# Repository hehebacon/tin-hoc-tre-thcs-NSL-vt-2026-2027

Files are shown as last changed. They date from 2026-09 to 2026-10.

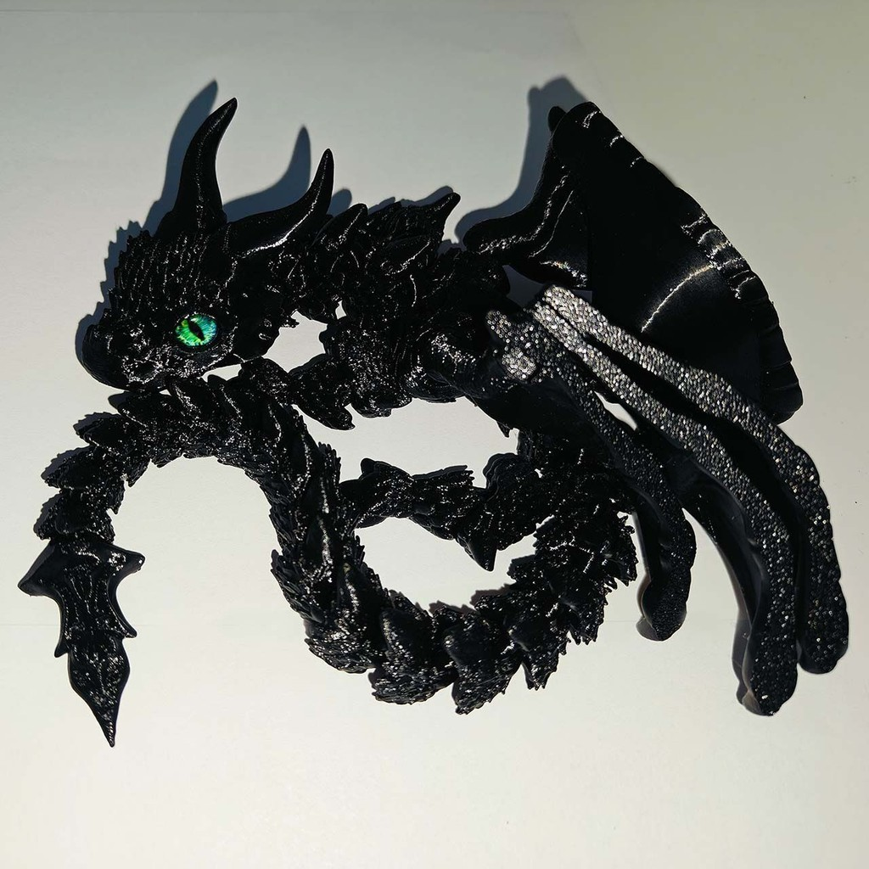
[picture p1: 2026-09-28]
dragon-1.png

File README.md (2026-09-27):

# AI Quadruped Robot - Servo Controller

Current firmware stage:

- ESP32 target
- 4 legs / 12 logical servo channels
- Inverse kinematics module
- Per-servo calibration
- Servo manager
- Serial command/debug interface
- Hardware-independent simulation stage

## Folder

```text
servo_controller/
├── servo_controller.ino
├── config.h
├── Kinematics.h
├── Kinematics.cpp
├── ServoCalibration.h
├── ServoCalibration.cpp
├── ServoManager.h
├── ServoManager.cpp
└── README.md
```

## Arduino IDE

Open:

```text
servo_controller.ino
```

Select the ESP32 board already being used by the project and press Verify.

No PCA9685 library is required yet because the current ServoManager is a software/simulation layer.

## Serial

Baud:

```text
115200
```

Commands:

```text
help
debug
status
center
enable
disable

servo 0 90
leg FL 90 90 90

cal
cal 0
caloffset 0 5
calinvert 1 1
callimit 2 10 170

ik 80 0 -100
ikleg FL 80 0 -100
```

## Important

Do not connect or power real servos yet.

The next hardware stage is:

```text
ServoManager
    ↓
PCA9685
    ↓
12 servos
```

That stage will require correct power wiring and current handling.

## Current firmware architecture (v0.4.0)

The firmware now contains:
- hardware-independent quadruped core, kinematics, gait and servo calibration
- deterministic offline competition DecisionEngine
- Perception / WorldState abstraction for line, obstacle, target and color
- color and line sensor adapter interfaces
- local Vietnamese/English offline command AI
- ESP32 Wi-Fi AP + optional STA Internet connection
- optional Gemini online assistant with offline fallback
- web dashboard and telemetry
- safety layer remains authoritative over motion

Online AI is optional. Competition autonomy must not depend on Internet access.

Real-hardware status: the software interfaces are ready for integration, but sensor drivers, pickup/place hardware, field calibration and repeated real-robot testing are still required before claiming competition-ready hardware performance.

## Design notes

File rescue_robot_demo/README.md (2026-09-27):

# Rescue Robot Simulator V3

This directory contains the hardware-neutral rescue robot simulator and the
ESP32 motion boundary.

## What is included

- deterministic 50 ms simulator loop
- A* navigation with terrain cost
- alternating-diagonal quadruped gait
- gait movesets: IDLE, WALK, SLOW_WALK, SEARCH, RESCUE
- foot-target -> hardware-aligned IK -> joint-angle telemetry
- live leg moveset/phase visualization and joint-angle display
- ESP32 MotionController gait execution
- calibration remains between IK and servo output
- E-STOP / resume path
- telemetry and serial command protocol
- unit tests for navigation, gait and safety

## Motion architecture

Simulator:

    mission/path
        -> GaitPlanner
        -> FootTarget
        -> QuadrupedIK (45/75/105 mm)
        -> joint angles

ESP32:

    GaitController
        -> FootTarget
        -> MotionController
        -> Kinematics
        -> ServoCalibration
        -> ServoManager
        -> PCA9685

The simulator is not a replacement for mechanical calibration. Before real
servo power-up, verify every leg's direction, limits, neutral angle and physical
clearance at low speed.

## Run

    ./run.sh

## Test

    python3 -m unittest discover -s . -p 'test_*.py'

## Serial gait commands

    gait WALK
    gait SLOW_WALK
    gait SEARCH
    gait RESCUE
    stop
    resume

JSON command example:

    {"command":"GAIT","mode":"WALK"}

## Safety

Never treat simulator reachability as proof that a physical pose is safe.
Mechanical limits, power/current limits and calibration must be verified on the
real robot.

## Simulator validation status

The simulator now exposes the same nominal leg geometry documented for the
physical robot:

- Coxa: 45 mm
- Femur: 75 mm
- Tibia: 105 mm

The Python IK layer is used for reachability and telemetry only. The ESP32
Kinematics module remains authoritative for physical servo output and limits.

The UI shows each leg's gait phase plus C/F/T joint angles while the robot
moves. This makes gait changes visible before hardware power-up.

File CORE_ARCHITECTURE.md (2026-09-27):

# Robot Core Architecture\n\n## Autonomous Core\n\nThe firmware now has an offline mission-level decision layer above locomotion.\n\nArchitecture:\n\nSensors -> RobotCore -> DecisionEngine -> MotionSafety -> MotionController -> GaitController -> IK -> calibration -> PCA9685 -> 12 servos\n\nDecisionEngine receives state feedback from sensors through RobotCore. It chooses the next high-level action; it never writes PWM or raw servo angles.\n\n## Offline decision engine\n\n`DecisionEngine` is deterministic C++ firmware. It does not use an AI API, Internet connection, cloud service, or token.\n\nExample:\n\ngoal RESCUE -> SEARCH -> target detected -> RESCUE -> rescue complete -> RETURN_HOME\n\n## Goals\n\n- RESCUE\n- PATROL\n- RETURN_HOME\n- DEMO\n\n## Actions\n\n- IDLE\n- SEARCH\n- APPROACH\n- RESCUE\n- RETURN_HOME\n- PATROL\n- DEMO\n- FAULT\n\n## Serial commands\n\ngoal RESCUE\ngoal PATROL\ngoal RETURN_HOME\ngoal DEMO\nfound\nrescue_done\nhome\nai_status\nreset_mission\n\nJSON example: {"command":"GOAL","goal":"RESCUE"}\n\nExisting low-level mission and gait commands remain available for testing.\n\n## Feedback loop\n\ngoal -> decision -> motion -> sensor reading -> decision again\n\nA target detection is latched so a brief sensor detection is not immediately lost.\n\n## Safety\n\n- MotionSafety has priority over the decision engine.\n- E-STOP disables motion.\n- Motion timeout enters E-STOP.\n- Sensor sanity violations can move RobotCore into FAULT.\n- A mission cannot start while motion safety is blocked.\n- The decision engine cannot bypass servo calibration or MotionSafety.\n\n## Current boundary\n\nThis is an offline autonomous decision layer, not a general-purpose generative AI.\n\nReal autonomous navigation still requires physical perception and localization. Simulator path planning must not be presented as proof that the physical robot can navigate without those sensors.\n\n## Development rule\n\nKeep the architecture modular: Mission/Decision -> MotionController -> Kinematics -> Calibration -> Servo driver.\n\nThis allows simulator and future hardware backends to share the same mission logic.

## AI + Perception extension

The core is extended with a Perception layer that normalizes sensors into WorldState. WorldState feeds the deterministic DecisionEngine. An optional OnlineAIClient can provide Gemini-based operator assistance over Wi-Fi, but it never bypasses RobotCore or MotionSafety.

Flow:
Sensors -> Perception -> WorldState -> Offline DecisionEngine -> RobotCore -> MotionController

Optional:
Web UI -> OnlineAIClient/Gemini -> advice -> operator/validated command -> RobotCore

Wi-Fi uses AP + optional STA so local control remains available when Internet is unavailable.

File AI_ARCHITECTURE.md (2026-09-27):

# XZORT RESCUE QUADRUPED — AI ARCHITECTURE

## Offline AI
The ESP32 remains autonomous without Internet:
- deterministic competition state machine
- line/intersection decisions
- obstacle handling
- pickup/classify/place states
- home/end-game transitions
- fault and safety handling
- Vietnamese/English local intent parser

Gemini is never required for the competition mission.

## Online AI — Gemini
When Wi-Fi has Internet, Gemini provides:
- natural-language chat
- state explanation
- diagnostics
- telemetry interpretation
- planning/debug suggestions

Online responses are advisory and do not directly write servo positions.

## Perception
Sensors are normalized into WorldState:
- line state and intersection
- obstacle and distance
- target detection
- pickup/place state
- target color and confidence
- home/end-game state
- sensor health

ColorSensorInterface and LineSensorInterface are hardware-independent adapters. Real sensor drivers can replace them without changing DecisionEngine.

## Safety boundary
Online AI -> advice/intent -> validated RobotCore -> MotionSafety -> MotionController

Competition path:
Sensors -> Perception -> WorldState -> DecisionEngine -> RobotCore -> MotionController

If Internet fails, the competition path remains available.

## Wi-Fi
ESP32 uses AP + STA:
- AP: XZORT-RESCUE for local control
- STA: optional configured router/hotspot for Internet
- AP remains available when STA is unavailable

No Wi-Fi or Gemini secret is stored in the public source.

## Remaining real-world work
Software interfaces are in place, but competition readiness still requires real sensor drivers, a real pickup/place mechanism, field calibration, real servo integration, and repeated end-to-end testing.

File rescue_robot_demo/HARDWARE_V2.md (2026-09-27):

# Hardware V2 Integration

V1 is software-complete. V2 is the physical integration layer.

## Hardware chain

ESP32 -> PCA9685 -> 12 servos
       -> IMU
       -> environmental sensor
       -> network link

Optional companion computer:

camera -> Robot OS
thermal -> Robot OS

## Motion

The Python GaitPlanner produces logical foot targets.

The ESP32 Kinematics module converts:

    foot X/Y/Z
        -> coxa/femur/tibia
        -> calibrated servo angles

ServoManager is the hardware boundary.

## Safety requirements

Before powering a real mechanism:

- lift the robot clear of the ground for initial servo tests
- use conservative mechanical limits
- test one servo/channel at a time
- keep an accessible physical power cutoff
- never rely on software E-STOP as the only safety mechanism
- verify servo orientation and calibration before gait testing

The repository does not assume that simulated angles are safe mechanical angles.

## Firmware adapter status

The firmware now contains guarded adapters for PCA9685, IMU and environmental sensing. PCA9685 output remains disabled by default (`ENABLE_PCA9685 0`). Physical activation requires the matching library, verified wiring, servo calibration and conservative mechanical limits.

A firmware motion timeout and local E-STOP latch are also present so the network link is not the only safety layer.

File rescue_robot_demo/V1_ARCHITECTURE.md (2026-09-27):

# Rescue Robot V1 Architecture

    WEB COMMAND CENTER
             |
        REST API :8787
             |
      +------+------+
      |             |
  Mission       Safety
      |             |
      +-- Robot Core+
             |
       Decision Engine
     /       |       \
 PATROL   RESCUE   AUTONOMOUS
             |
        Sensor Fusion
    /       |       |       \
  RGB    THERMAL   ENV      IMU
             |
      Hardware Adapter
             |
        ESP32 / Servos

## V1 status

- Offline simulation: complete
- A* navigation: complete
- Four operating modes: complete
- Mission lifecycle: complete
- Emergency stop / resume / return-home: complete
- Camera + thermal simulation: complete
- Environment telemetry: complete
- Battery / signal / IMU / GPS simulation: complete
- Web command center: complete
- ESP32 transport boundary: ready
- Real sensor drivers: hardware phase
- Real servo/PCA9685 output: hardware phase

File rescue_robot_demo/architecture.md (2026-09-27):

# Rescue Robot Architecture

## Mission
A modular quadruped platform for search-and-rescue, environmental awareness, telemetry and authorized/public-data-assisted operations.

## Runtime layers
1. Firmware / motion: ESP32, servo controller, inverse kinematics and calibration.
2. Sensor layer: RGB camera, thermal sensor, IMU and environmental sensors.
3. Robot core: state, safety, motion requests and telemetry.
4. Decision layer: patrol, rescue, autonomous navigation and public/authorized data analysis.
5. Network layer: REST/WebSocket gateway.
6. Operator UI: live map, camera/thermal view, telemetry, mode control and logs.

## Design rule
Simulation providers must expose the same logical data shape as future hardware providers. This keeps the demo useful after hardware integration.

## OSINT boundary
The OSINT mode is designed around public or explicitly authorized information sources for emergency-response context. It is not a private-person tracking system.

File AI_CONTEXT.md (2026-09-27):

# AI CONTEXT — RESCUE QUADRUPED ROBOT

> Read this file before modifying the project. It is the persistent context for AI assistants working on this robotics project.

## 1. Project

This is a real student-built quadruped rescue robot for the Vietnamese Tin học trẻ competition.

- Competition: Tin học trẻ, THCS Ngô Sĩ Liên — Vũng Tàu, 2026–2027, Bảng B
- Repository: hehebacon/tin-hoc-tre-thcs-NSL-vt-2026-2027
- Goal: build a practical search-and-rescue quadruped prototype, not just a visual simulator.

Core concept:

PERCEIVE → UNDERSTAND → MOVE → SEARCH → DETECT → RESPOND → RESCUE

## 2. Robot

Physical architecture:

- 4 legs
- 3 DOF per leg
- 12 servos total
- ESP32 controller
- PCA9685 16-channel PWM driver

Legs:

- FL = Front Left
- FR = Front Right
- RL = Rear Left
- RR = Rear Right

Each leg:

Coxa → Femur → Tibia → Foot

Target servo: MG996R or mechanically/electrically compatible equivalent.

## 3. Servo mapping

Do not change casually:

FL: 0=Coxa, 1=Femur, 2=Tibia
FR: 3=Coxa, 4=Femur, 5=Tibia
RL: 6=Coxa, 7=Femur, 8=Tibia
RR: 9=Coxa, 10=Femur, 11=Tibia

## 4. IK geometry

Current geometry:

- Coxa: 45 mm
- Femur: 75 mm
- Tibia: 105 mm

These values must remain consistent across firmware, simulator, calibration, and CAD unless a deliberate redesign is requested.

## 5. Software architecture

Sensors
↓
RobotCore
↓
MotionSafety
↓
MotionController
↓
GaitController
↓
Inverse Kinematics
↓
Servo Calibration
↓
PCA9685
↓
12 Servos

RobotCore is the high-level mission/state layer. It should not directly control raw servo PWM.

MotionSafety has priority over mission logic. Never bypass E-STOP, safety limits, or fault handling.

MotionController converts foot targets into joint angles, calibration values, servo mapping, and PCA9685 commands.

## 6. Mission modes

Current modes:

IDLE
PATROL
SEARCH
RESCUE
FOLLOW
AVOID
EXPLORE
INSPECT
DELIVER
RECHARGE
RETURN_HOME
CALIBRATION
DEMO
CLIMB
FAULT

High-level intent:

- IDLE: stop
- PATROL: slow walking
- SEARCH: search gait
- RESCUE: rescue gait
- RETURN_HOME: return movement
- FOLLOW/AVOID/INSPECT: movement/search-style behavior
- EXPLORE/DEMO: walking/demo behavior
- CALIBRATION: stop and calibrate
- FAULT: stop
- CLIMB: placeholder only

These are software states. A mode does not prove the corresponding physical capability exists.

## 7. Gait

Current gait concepts:

- IDLE
- WALK
- SLOW_WALK
- SEARCH
- RESCUE

The gait uses alternating diagonal patterns such as FL+RR versus FR+RL.

Priorities:

1. Stability
2. Smooth movement
3. Predictable foot placement
4. Low servo shock
5. Repeatability

## 8. Sensors

Planned/target sensors include:

- IMU, potentially MPU6050
- Distance sensors
- Environmental sensor
- ESP32 camera
- Thermal sensor

Important distinction:

A software interface or placeholder does not mean hardware is installed.

Camera ≠ completed AI vision.
Thermal sensor ≠ automatic human detection.
Simulator pathfinding ≠ physical autonomous navigation.

## 9. Search/rescue flow

Conceptual mission:

PATROL → SEARCH → TARGET DETECTED → RESCUE → RETURN_HOME

Person/target detection may come from camera, thermal sensing, or other validated sensors.

Detection may be latched until mission reset so a short detection is not immediately lost.

## 10. Simulator

Simulator directory:

rescue_robot_demo/

Important files:

- core.py
- gait.py
- main.py
- test_core.py
- esp32_link.py
- PROTOCOL_V1.md
- ESP32_BRIDGE.md
- README.md
- VERSION

The simulator models mission state, gait, rescue flow, safety, terrain/path planning, and ESP32 communication.

Always distinguish:
- IMPLEMENTED
- SIMULATED
- PLANNED
- HARDWARE DEPENDENT
- PLACEHOLDER

Never present simulated functionality as physically verified.

## 11. Path planning

The simulator includes A*-style pathfinding with terrain costs.

This is simulation functionality. Real autonomous navigation requires physical sensing, localization, perception, obstacle detection, and control.

## 12. CLIMB

CLIMB is currently a software placeholder.

The physical robot does NOT currently have a verified wall-climbing mechanism.

Do not invent or claim wall climbing capability.

Any future climbing system requires an actual mechanical mechanism and dedicated control/safety design.

## 13. Power

12 high-current servos must not be powered directly from the ESP32.

Expected architecture:

Battery
├── dedicated servo power rail → 12 servos/PCA9685 V+
└── regulated logic power → ESP32

Use a correctly sized power system and appropriate common grounding/protection. Do not underspec the power system merely to save cost.

## 14. Mechanical/CAD rules

The robot should be compact, rigid, modular, repairable, and realistically manufacturable.

CAD should provide mounting/access for:

- ESP32
- PCA9685
- battery
- power converter/BEC
- camera
- sensors
- wiring

Battery and heavy electronics should stay near the body center to maintain a stable center of gravity.

Priorities:

1. Mechanical stability
2. Feasibility
3. Servo compatibility
4. Center of gravity
5. Ground clearance
6. Cable management
7. Electronics access
8. Sensor visibility
9. Weight
10. Appearance

## 15. AI rules

When assisting this project:

1. Treat it as a real physical engineering project.
2. Do not invent hardware or claim unverified capabilities.
3. Explicitly label simulation-only, planned, placeholder, and hardware-dependent features.
4. Preserve the existing architecture unless a redesign is explicitly requested.
5. Check dependent files when changing shared interfaces, servo mapping, IK dimensions, commands, or telemetry.
6. Never bypass MotionSafety or E-STOP.
7. Prefer practical, testable, modular solutions over unnecessary complexity.
8. Do not add advanced frameworks or hardware simply to make the project sound impressive.
9. Do not claim firmware compilation/tests succeeded unless they were actually run.
10. When making substantial source changes, provide complete replacement files when practical.

## 16. Development workflow

For code changes:

1. Inspect the current repository/source first.
2. Identify all affected files.
3. Implement the complete change.
4. Validate what can actually be validated.
5. Update related documentation/tests.
6. Commit the change to GitHub.
7. Report the commit and exactly what was changed.
8. Clearly state anything that could not be verified.

## 17. Current priority

Do not try to implement everything at once.

Priority:

Stable standing
→ Reliable walking
→ Turning
→ Sensor integration
→ Search
→ Target detection
→ Rescue behavior
→ Autonomous navigation
→ Advanced capabilities

A reliable physical robot is more valuable than a large collection of unfinished features.

## 18. Future expansion

Potential future modules include:

- Computer vision
- Thermal perception
- Obstacle avoidance
- Localization
- SLAM
- Autonomous navigation
- Mapping
- Terrain-adaptive gait
- Remote control
- Mission planning
- AI assistance
- Advanced climbing

These are future directions unless the repository shows otherwise.

## 19. Short identity

This is a 12-DOF ESP32/PCA9685 quadruped rescue robot with modular mission control, gait, inverse kinematics, calibration, safety, and sensor layers. It is being developed as a real Tin học trẻ competition prototype. Keep simulation separate from physical capability, never invent hardware, never bypass safety, and prefer practical complete-file changes.

## Latest extension status

v0.4.0 adds Perception, WorldState, color/line sensor adapters, Gemini OnlineAIClient, AP+STA Wi-Fi, and a web dashboard that reports perception and online AI status. No credentials are committed.

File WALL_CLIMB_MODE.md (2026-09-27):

# Wall Climb Mode

The robot now exposes a `CLIMB` mission mode in the mission state machine.

## Safety / capability boundary

`CLIMB` is currently a **capability placeholder**. Selecting the mode does not command the normal leg gait and therefore does not pretend that the current quadruped hardware can climb a wall.

Current behavior:

- Mission mode becomes `CLIMB`.
- Normal gait output is stopped.
- Simulator shows the mode as wall-climb standby.
- The mode can later be connected to a dedicated climbing controller after the physical mechanism, adhesion/traction sensing, fall detection, and limits have been validated.

This keeps the mission API ready without inventing hardware capabilities that have not been measured or installed.

## Command

Serial:

```
mission CLIMB
```

JSON:

```json
{"command":"MISSION","mode":"CLIMB"}
```

Return to normal operation with another supported mission mode or:

```
mission IDLE
```

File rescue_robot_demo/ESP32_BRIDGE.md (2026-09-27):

# ESP32 Bridge

The Python Robot OS talks to the ESP32 through a newline-delimited JSON
boundary. The ESP32 is the authoritative safety boundary for physical motion.

## PC -> ESP32

Safety:

    {"type":"command","command":"STOP"}
    {"type":"command","command":"RESUME"}

Pose:

    {"type":"pose","leg":"FL","x":80,"y":45,"z":-90}

Gait:

    {"type":"command","command":"GAIT","mode":"WALK"}

Supported gait modes:

- WALK
- SLOW_WALK
- SEARCH
- RESCUE

## ESP32 -> PC

Telemetry contains firmware, E-STOP state, gait mode, gait phase, movement
state and hardware status.

The Python side must treat an active E-STOP or safety timeout as authoritative
and must never assume that a simulator command means the physical robot moved.

## Hardware integration order

1. ESP32 motion firmware
2. Serial/USB transport
3. Servo/PCA9685 output
4. IMU
5. Environmental sensor
6. RGB camera
7. Thermal sensor
8. Real network transport

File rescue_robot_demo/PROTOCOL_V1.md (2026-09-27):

# Robot OS Protocol V1

All packets are newline-delimited JSON.

## Telemetry

    {"type":"telemetry","firmware":"0.3.0","safety_stop":false,"gait":"WALK","phase":0.25,"moving":true,"hardware":{...}}

The ESP32 safety state is authoritative.

## Command envelope

    {"type":"command","command":"STOP"}

## Safety / pose commands

Supported commands:

- STOP
- RESUME
- ENABLE
- CENTER
- STAND

## Gait command

    {"type":"command","command":"GAIT","mode":"WALK"}

Supported gait modes:

- WALK
- SLOW_WALK
- SEARCH
- RESCUE

The ESP32 validates the mode and safety state before starting motion.

## Foot target

    {"type":"pose","leg":"FL","x":80,"y":45,"z":-90}

The ESP32 is responsible for IK reachability, software limits, calibration and
physical servo output. Simulator reachability is not a hardware safety proof.

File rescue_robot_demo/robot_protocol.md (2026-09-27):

# Robot Protocol V1

The demo uses a small JSON telemetry/control protocol so the simulator can later be replaced by an ESP32 transport.

## Telemetry

```json
{
  "type": "telemetry",
  "robot": {"x": 2, "y": 2},
  "mode": "PATROL",
  "found": false,
  "sensors": {
    "temperature": 31.2,
    "humidity": 78.0,
    "pressure": 1007.0,
    "thermal": 0.0,
    "person_visible": false
  }
}
```

## Commands

- `{"type":"mode","mode":"PATROL"}`
- `{"type":"mode","mode":"RESCUE"}`
- `{"type":"mode","mode":"OSINT"}`
- `{"type":"mode","mode":"AUTONOMOUS"}`

Hardware transport is intentionally separated from robot logic.

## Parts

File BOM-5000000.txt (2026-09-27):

# RESCUE ROBOT — BOM 5,000,000 VND HARD CAP
Project: Tin học trẻ THCS Ngô Sĩ Liên — Vũng Tàu 2026–2027
Target: quadruped rescue robot, 4 legs / 12 DOF
Budget ceiling: EXACTLY 5,000,000 VND
Pricing checked: September 2026
Note: prices are reference prices found online and can change; shipping is not included.

## 1. ACTUATORS
| Item | Qty | Unit (VND) | Subtotal |
|---|---:|---:|---:|
| DS3218MG 20KG metal-gear servo | 12 | 205,000 | 2,460,000 |

Servo reference: Shopee listing checked at 205,000 VND for DS3218 20KG.
A higher-end DS3218Pro reference was also found at 320,000 VND, but 12 units would break the 5M cap.
For this hard-cap build, use the 20KG class servo and validate actual torque under the final robot mass/geometry before purchase.

## 2. CONTROL / ELECTRONICS
| Item | Qty | Unit (VND) | Subtotal |
|---|---:|---:|---:|
| ESP32 DevKit | 1 | 109,000 | 109,000 |
| PCA9685 16-channel servo driver | 1 | 90,000 | 90,000 |
| 3.5-ish inch class TFT touch display | 1 | 258,409 | 258,409 |
| MPU6050 IMU | 1 | 68,000 | 68,000 |
| BME280 | 1 | 45,135 | 45,135 |
| MLX90614 IR thermal sensor | 1 | 167,045 | 167,045 |
| VL53L0X ToF distance sensor | 3 | 39,400 | 118,200 |
| ESP32-CAM / OV2640 camera board | 1 | 170,000 | 170,000 |

## 3. POWER
| Item | Qty | Unit (VND) | Subtotal |
|---|---:|---:|---:|
| ZTW UBEC 6A / 10A max, 2S–6S | 1 | 223,608 | 223,608 |
| 2S 7.4V 2200mAh 30C LiPo | 1 | 190,000 | 190,000 |
| XL4015 5A buck converter | 1 | 35,000 | 35,000 |
| E-STOP / master switch / fuse hardware | 1 set | 50,000 | 50,000 |

IMPORTANT POWER NOTE:
- Servo rail must be separated from the ESP32 logic rail.
- The UBEC feeds the servo rail.
- The buck feeds logic/display as appropriate.
- Do NOT power the 12 servos from the ESP32 or a small 5V regulator.
- Actual current demand must be tested before full-load operation.

## 4. MECHANICAL
| Item | Qty | Budget (VND) |
|---|---:|---:|
| Load-bearing aluminum/frame material | 1 set | 350,000 |
| PETG/nylon 3D printed shell/brackets | 1 set | 300,000 |
| Shafts + bearings + servo horns + screws | 1 set | 220,000 |
| LED + buzzer + connectors + wiring + capacitors | 1 set | 100,000 |

## 5. BUDGET RESERVE
| Item | Budget |
|---|---:|
| Small price/consumable reserve | 5,603 VND |

## TOTAL
Actuators:        2,460,000
Electronics:      1,025,789
Power:              498,608
Mechanical:         970,000
Reserve:              5,603
--------------------------------
TOTAL:            4,960,000 VND

## FINAL 40,000 VND GAP
Keep 40,000 VND unallocated as an intentional contingency for price movement / small hardware.

HARD CAP:
5,000,000 VND maximum.

## CURRENT CHECKED PRICE REFERENCES
- DS3218 20KG: 205,000 VND reference
- DS3218Pro 20KG: 320,000 VND reference
- ESP32 DevKit: about 109,000–129,000 VND
- PCA9685: about 90,000–122,000 VND
- 2.4/2.8-inch ESP32 TFT touch boards: about 258,409–278,409 VND
- MPU6050: 68,000 VND reference
- BME280: about 45,135 VND reference
- MLX90614: about 167,045 VND reference
- VL53L0X: 39,400 VND reference
- ESP32-CAM: about 170,000 VND reference
- ZTW UBEC 6A / 10A max: about 223,608 VND reference
- 2S 7.4V 2200mAh 30C LiPo: 190,000 VND reference
- XL4015 5A buck: 35,000 VND reference

## ENGINEERING STATUS
IMPLEMENTED / PLANNED:
- 12-servo quadruped architecture
- ESP32 + PCA9685 control architecture
- IMU / environmental / distance / thermal / camera interfaces
- separate servo and logic power architecture
- 80cm-class physical design documented in robot-out.txt

HARDWARE DEPENDENT:
- final servo torque margin
- actual battery runtime
- final frame mass
- thermal/camera performance
- exact screen mounting
- final mechanical dimensions

This BOM is a budget target, not a claim that every listed price will remain available at purchase time.

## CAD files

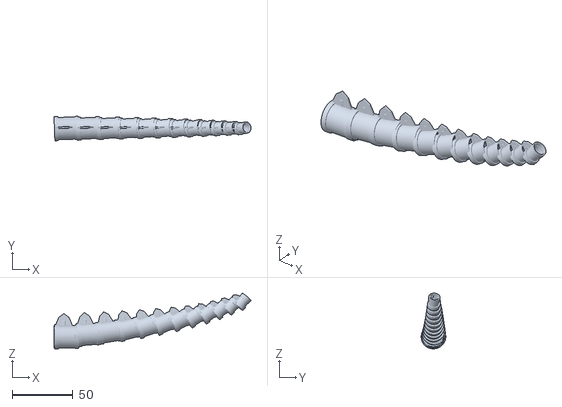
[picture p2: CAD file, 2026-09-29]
out/PRINT/tail.stl
162.3 x 20.3 x 46.0

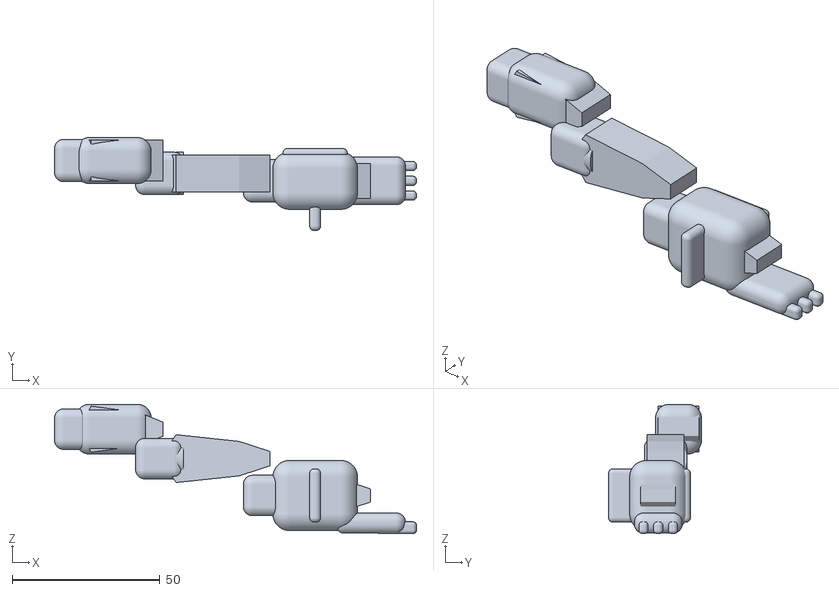
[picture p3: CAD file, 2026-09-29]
out/PRINT/FL_leg.stl
122.5 x 31.5 x 43.8

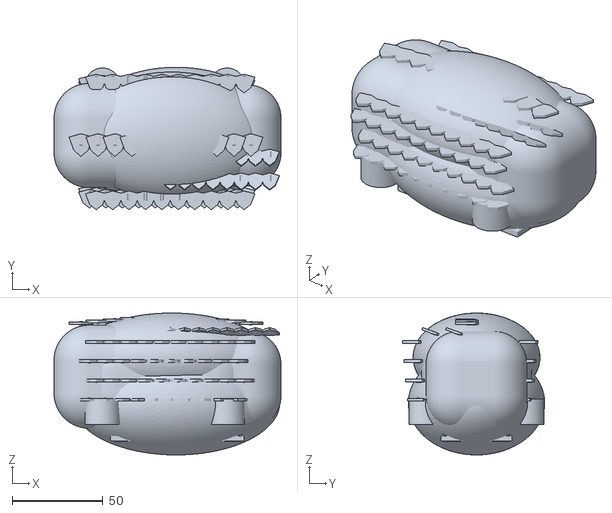
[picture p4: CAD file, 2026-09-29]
out/PRINT/body.stl
124.9 x 78.4 x 78.1

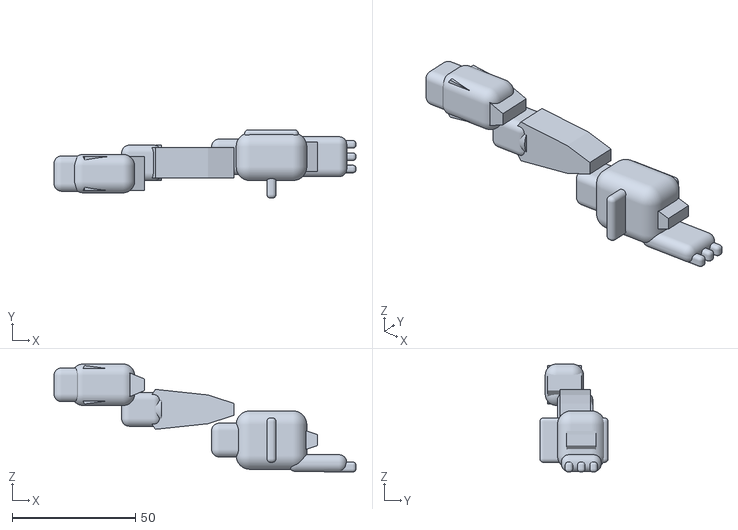
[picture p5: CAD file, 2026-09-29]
out/PRINT/RR_leg.stl
122.5 x 27.8 x 43.8

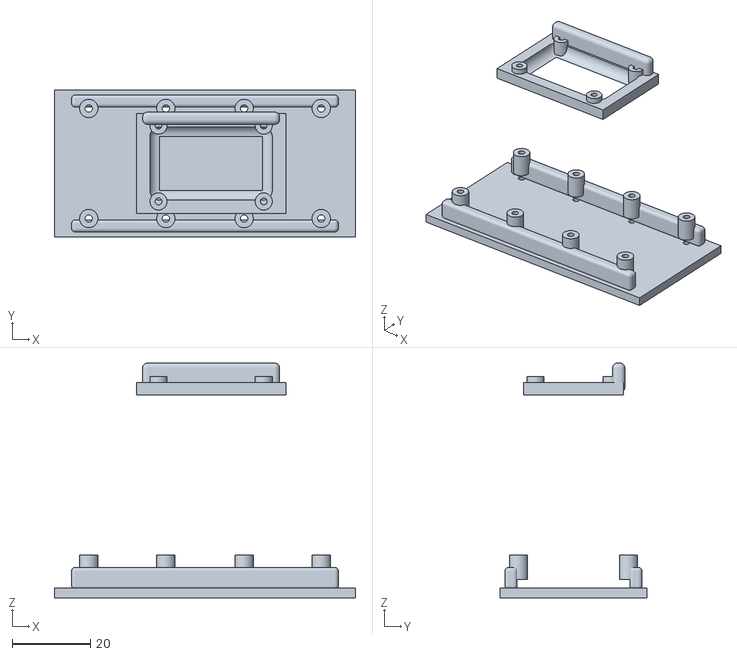
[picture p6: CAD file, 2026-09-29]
out/PRINT/electronics.stl
76.7 x 37.4 x 59.9

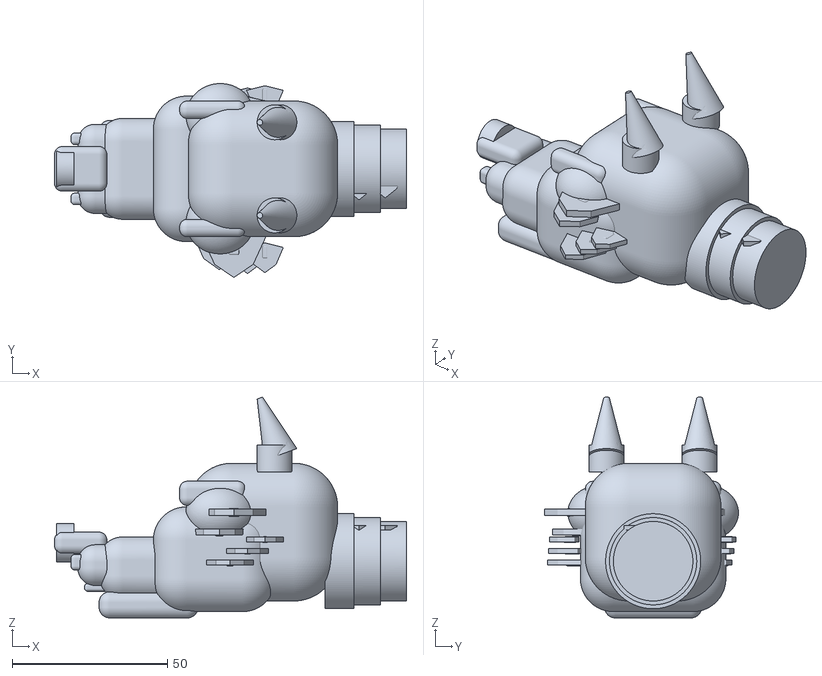
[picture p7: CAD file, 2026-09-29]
out/PRINT/head.stl
113.2 x 62.4 x 71.0

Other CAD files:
out/PRINT/RL_leg.stl
out/PRINT/FR_leg.stl

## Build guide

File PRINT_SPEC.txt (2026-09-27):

RESCUE QUADRUPED — FDM PRINT V4 / DRAGON BODY
==============================================================

DESIGN
- Dragon-style central body with armored spine
- Rear articulated tapering dragon tail
- Separate tail modules for easier printing/replacement
- Dragon head with drilled eye openings
- Tapered leg links with structural ribs

MODEL
Nominal robot height: 800.0 mm
Body: 145.0 x 250.0 x 72.0 mm
Thigh: 180.0 mm
Shin: 200.0 mm
Tail modules: 6 + tip
Eye hole diameter: 8.0 mm

PRINT FILES
- Dragon body
- Dragon head with eye holes
- Dragon hip brackets
- Dragon thigh links
- Dragon knee/shin links
- Tail modules 01-06
- Tail tip

FDM STARTING PROFILE
- Layer height: 0.20 mm
- Walls: 4+
- Infill: 30-50% for structural prototypes
- PETG or another mechanically suitable material
- Print one body/leg/tail test before full production
- Verify real servo and fastener dimensions before final print

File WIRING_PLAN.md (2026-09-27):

# Robot V2 Wiring Plan

This is the planned wiring for an ESP32 DevKit-style controller. Pin labels vary by board, so verify the exact board pinout before connecting power.

## Power architecture

- Servos: separate regulated servo supply sized for the actual servo model.
- ESP32: regulated 5 V USB/VIN input as specified by the board.
- PCA9685 logic: 3.3 V-compatible I2C logic.
- All signal grounds must share a common reference.
- Do not power a bank of 12 servos from the ESP32 3.3 V or USB rail.

## I2C bus

| Device | ESP32 |
|---|---|
| PCA9685 SDA | GPIO 21 |
| PCA9685 SCL | GPIO 22 |
| IMU SDA | GPIO 21 |
| IMU SCL | GPIO 22 |
| Environmental SDA | GPIO 21 |
| Environmental SCL | GPIO 22 |

I2C devices share SDA/SCL and must have non-conflicting addresses.

## PCA9685 servo map

| Leg | Coxa | Femur | Tibia |
|---|---:|---:|---:|
| FL | 0 | 1 | 2 |
| FR | 3 | 4 | 5 |
| RL | 6 | 7 | 8 |
| RR | 9 | 10 | 11 |

Servo channel numbering is logical. The physical servo orientation must be calibrated before gait testing.

## Sensors

Recommended first hardware layer:

- IMU: MPU6050/compatible I2C IMU
- Environment: BME280/compatible I2C sensor
- Thermal: MLX90640/compatible thermal array on a companion path
- RGB camera: companion camera/ESP32-CAM or SBC camera

The repository keeps these behind interfaces so sensor libraries can be swapped without rewriting mission logic.

## Network

For the first hardware test:

ESP32 USB serial -> PC Robot OS

Only after serial telemetry and safety behavior are verified should Wi-Fi/network control be enabled.

## Mandatory safety sequence

1. Keep PCA9685 output disabled in firmware.
2. Connect one servo only.
3. Verify common ground.
4. Verify servo voltage separately.
5. Test center command with the mechanism unloaded.
6. Calibrate that channel.
7. Repeat one channel at a time.
8. Add the remaining servos.
9. Test one leg.
10. Test all four legs without walking.
11. Test gait with the robot physically secured/raised.
12. Only then perform slow ground tests.

A physical power cutoff must remain accessible. Software E-STOP is not the only safety mechanism.

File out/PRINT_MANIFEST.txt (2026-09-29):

XZORT RESCUE DRAGON-LIZARD — 35cm / 12 DOF
==============================================================================

GENERATED CAD
  Physical output: grouped STL modules
  Reference output: one full-assembly STEP
  No per-scale STL/STEP explosion

SIZE LOCK
  Hard maximum: 350.0 mm
  Safety target: 345.0 mm
  Uniform scale factor: 0.31182513

ASSEMBLY BOUNDING BOX
  Before scale: X=1106.39 Y=309.00 Z=426.79 mm
  After scale : X=345.00 Y=96.35 Z=133.08 mm
  Maximum after scale: 345.00 mm

DESIGN LOCKS
  Dragon-lizard visual shell over a quadruped mechanism
  4 legs x 3 DOF = 12 servo positions
  Round external joint shields
  Layered dragon scales grouped into body/head/tail modules
  Dragon head with integrated camera-eye housings
  Electronics bay + removable tray
  Top display mount
  Articulated tapered tail
  NO WINGS / NO CANARDS / NO FIN-WINGS

PRINT MODULES
  PRINT/body.stl
  PRINT/head.stl
  PRINT/electronics.stl
  PRINT/FL_leg.stl
  PRINT/FR_leg.stl
  PRINT/RL_leg.stl
  PRINT/RR_leg.stl
  PRINT/tail.stl

REFERENCE
  REF/full_assembly.step

RAW LOGICAL PART COUNT
  166 generated solids/components
  8 printable STL groups

IMPORTANT
  Verify real servo, battery, PCB, camera and display dimensions
  before manufacturing.

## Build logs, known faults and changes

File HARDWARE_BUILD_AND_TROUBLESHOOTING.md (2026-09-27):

# XZORT Rescue Quadruped — Hardware, Assembly & Troubleshooting

> Project: Tin học trẻ THCS Ngô Sĩ Liên — Vũng Tàu 2026–2027
>
> Robot: 4-legged quadruped, 12 logical servo channels, ESP32-based controller.
>
> This document is the practical guide for moving from simulator/firmware to a real prototype.

## 1. Architecture

    XZORT RESCUE QUADRUPED
             |
           ESP32
     RobotState / Motion
     Kinematics / Sensors
             |
          I2C/PWM
             |
          PCA9685
             |
      12 servo channels
             |
       4 legs x 3 DOF

Power:

    Servo supply -> fuse/switch -> servo power rail -> servos
    ESP32 supply -> regulated 5V/USB path
    Common GND -> ESP32 + PCA9685 + servo supply

IMPORTANT: never use the ESP32 as the power source for 12 physical servos. Select the servo supply from the actual servo voltage and current specifications.

## 2. Hardware purchase checklist

### Controller

- [ ] ESP32 development board x1
- [ ] USB data cable x1
- [ ] PCA9685 16-channel PWM board x1
- [ ] Spare wires/connectors
- [ ] Terminal blocks as needed

### Actuation

- [ ] 12 compatible servos
- [ ] 2–4 spare servos
- [ ] Servo horns
- [ ] Servo brackets
- [ ] Mechanical linkages
- [ ] M3/M4 hardware as required by the mechanical design

Do not buy/install all 12 servos before proving one complete leg.

Recommended order:

    1 complete leg
        -> 1 servo per joint
        -> 3-DOF leg
        -> 4-leg mechanical test
        -> full 12-servo build

### Power

- [ ] Servo-rated DC supply/battery
- [ ] DC-DC regulator if required
- [ ] Main power switch
- [ ] Fuse or suitable over-current protection
- [ ] Power distribution block
- [ ] Correct-gauge wiring
- [ ] Separate regulated ESP32 supply if required
- [ ] Multimeter

### Sensors

- [ ] IMU
- [ ] Distance sensors
- [ ] Optional camera
- [ ] Optional environmental/thermal sensor
- [ ] Buzzer/status LED
- [ ] Emergency-stop input

The simulator should provide software equivalents before hardware sensor integration.

### Mechanical

- [ ] Main chassis
- [ ] 4 leg assemblies
- [ ] Electronics mounting plate
- [ ] Battery mount
- [ ] Cable-management points
- [ ] Protective covers
- [ ] Rubber feet/contact pads

## 3. Assembly sequence

### Phase A — electronics bench test

    ESP32
      |
    PCA9685
      |
    ONE servo

Verify I2C, PWM, enable/disable, center position and conservative movement limits.

### Phase B — one joint

Test one servo at a time.

Verify:

- direction
- center
- limits
- no mechanical collision
- no abnormal noise or heating

### Phase C — one complete leg

    Hip
      |
    Thigh
      |
    Knee

Run the kinematics module and compare requested coordinates with actual movement.

### Phase D — four legs

    FL = Front Left
    FR = Front Right
    RL = Rear Left
    RR = Rear Right

Verify all 12 logical channels.

### Phase E — calibration

Calibrate before walking.

### Phase F — movesets

Test:

    stand
    sit
    center
    lift_leg
    place_leg
    step_forward
    step_backward
    turn_left
    turn_right

### Phase G — rescue behavior

Only after locomotion is stable:

    sensor input
        -> RobotState
        -> RescueController
        -> MotionController
        -> servo output

## 4. Module integration

Recommended dependency direction:

    main
     |
     +-- RobotState
     |
     +-- SensorManager
     |
     +-- RescueController
     |
     +-- MotionController
            |
            +-- Kinematics
            |
            +-- ServoManager
                   |
                   +-- PCA9685 / hardware driver

### RobotState

Stores current state such as:

    enabled
    emergencyStop
    batteryVoltage
    bodyX/bodyY/bodyZ
    sensorWarning
    rescueMode

Keep shared state here instead of scattering global variables.

### Kinematics

Input:

    target X/Y/Z

Output:

    joint angles

Kinematics should not contain PWM or I2C code.

### ServoManager

Responsible for:

- logical servo IDs
- angle limits
- inversion
- offsets
- simulation output
- hardware output
- enable/disable

### MotionController

Responsible for:

- standing
- stepping
- turning
- leg movement
- interpolation
- movesets

It calls Kinematics and ServoManager instead of directly manipulating PCA9685 channels.

### SensorManager

Responsible for reading sensors, validating readings and updating RobotState.

A bad sensor reading must not directly command a servo.

### RescueController

High-level behavior:

    IDLE
      -> PATROL
      -> TARGET_DETECTED
      -> APPROACH
      -> STOP_NEAR_TARGET
      -> REPORT / ASSIST

Start with deterministic, testable behavior. AI can be added later.

## 5. Servo channel map

Keep one fixed logical mapping.

| ID | Leg | Joint |
|---:|---|---|
| 0 | FL | Hip |
| 1 | FL | Thigh |
| 2 | FL | Knee |
| 3 | FR | Hip |
| 4 | FR | Thigh |
| 5 | FR | Knee |
| 6 | RL | Hip |
| 7 | RL | Thigh |
| 8 | RL | Knee |
| 9 | RR | Hip |
| 10 | RR | Thigh |
| 11 | RR | Knee |

Initially map logical ID N to PCA9685 channel N.

If physical wiring differs, change the mapping/configuration rather than rewriting MotionController.

## 6. Calibration

Start with the robot lifted off the ground.

Record for every servo:

    servo ID
    center
    offset
    invert
    minimum
    maximum

Example configuration concept:

    center = 90
    offset = 0
    invert = false
    minAngle = 20
    maxAngle = 160

These are examples only. Use the actual mechanical limits of the installed servo/joint.

Procedure:

1. Move every servo to a conservative center.
2. Test one joint at a time.
3. Check left/right symmetry.
4. Save calibration in project configuration.
5. Only then test standing.

## 7. Simulator and hardware

Use one MotionController for both environments.

    MotionController
          |
      ServoManager
          |
       +--+----------------+
       |                   |
    Simulator           Hardware
     backend             backend
                           |
                        PCA9685

Do not duplicate the walking algorithm for simulator and hardware.

## 8. Software installation

Arduino IDE:

1. Install Arduino IDE.
2. Install the ESP32 board package.
3. Open servo_controller/servo_controller.ino.
4. Select the exact ESP32 board.
5. Select the correct serial port.
6. Compile before connecting real servos.
7. Upload firmware.
8. Open Serial Monitor at 115200 baud.

Initial commands:

    help
    status
    debug
    center

## 9. Adding a module

Workflow:

    1. Define responsibility
    2. Create .h
    3. Create .cpp
    4. Add dependencies through constructors
    5. Add initialization
    6. Add update/tick method
    7. Add debug/status output
    8. Test in simulator
    9. Test one hardware component
    10. Integrate into full robot

Example interface:

    class NewSensor {
    public:
        bool begin();
        void update();
        bool healthy() const;
    };

Keep new modules small and single-purpose.

## 10. Troubleshooting

### ESP32 does not upload

Check:

- correct board
- correct serial port
- USB data cable
- board driver
- boot mode requirements
- whether another program owns the serial port

For upload debugging, disconnect external servo power first.

### PCA9685 is not detected

Check:

- SDA
- SCL
- GND
- VCC
- I2C address
- loose wires

Run an I2C scanner before changing servo code.

### Servo does not move

Check in this order:

    1. servo power
    2. common GND
    3. signal wire
    4. PCA9685 channel
    5. PWM frequency
    6. channel mapping
    7. angle limits
    8. calibration

### Servo moves in the wrong direction

Use the calibration inversion setting instead of rewriting the motion algorithm.

### Servo is offset

Use the per-servo offset instead of modifying the kinematics equations.

### One leg is mirrored

Check:

- left/right inversion
- mechanical mounting orientation
- logical channel mapping
- calibration offset

### Robot shakes

Possible causes:

- aggressive interpolation
- incorrect calibration
- loose mechanical joints
- inadequate servo power
- excessive mechanical load
- control-loop timing

Test one servo, then one leg, then four legs.

### ESP32 resets when servos move

Treat this as a power problem first.

Check:

    servo supply
    voltage sag
    current capability
    ground connection
    wiring
    regulator

Do not try to hide repeated brownouts with random software delays.

### Robot walks backward

Check:

- forward-direction convention
- coordinate system
- joint inversion
- gait phase order
- left/right mapping

### Robot falls

Debug in this order:

    calibration
      -> standing pose
      -> mechanical balance
      -> one-leg motion
      -> gait timing
      -> step height
      -> step length

Do not start autonomous gait testing before the static standing pose is stable.

## 11. Standard bug report

When something breaks, record:

    firmware version / commit
    board
    module
    exact command
    Serial Monitor output
    servo/channel ID
    expected behavior
    actual behavior
    simulator result
    hardware power state

Template:

    ## Bug

    Module:
    Commit:
    Hardware:
    Command:

    Expected:
    Actual:

    Serial output:

    Steps to reproduce:
    1.
    2.
    3.

## 12. Integration gates

    GATE 1  Code compiles
       |
    GATE 2  Simulator passes
       |
    GATE 3  ESP32 boots
       |
    GATE 4  PCA9685 communicates
       |
    GATE 5  One servo works
       |
    GATE 6  One joint calibrated
       |
    GATE 7  One complete leg works
       |
    GATE 8  Four legs stand
       |
    GATE 9  Basic gait works
       |
    GATE 10 Sensors work
       |
    GATE 11 Rescue behavior works
       |
    GATE 12 Full demo build

Never jump directly from simulator to full-power 12-servo testing.

## 13. Recommended documentation

Keep these files updated:

    README.md
    HARDWARE_BUILD_AND_TROUBLESHOOTING.md
    CALIBRATION.md
    TROUBLESHOOTING.md
    ARCHITECTURE.md
    CHANGELOG.md

## 14. Pre-demo checklist

### Hardware

- [ ] All 12 servos respond
- [ ] Calibration saved
- [ ] No cable can enter a moving joint
- [ ] Power connections secured
- [ ] Emergency stop / power switch tested
- [ ] Battery/supply checked

### Software

- [ ] Clean build
- [ ] Simulator test passed
- [ ] Servo mapping verified
- [ ] Standing pose verified
- [ ] Movesets verified
- [ ] Sensor simulation verified
- [ ] Rescue mode verified
- [ ] Serial debug available

### Demo flow

    BOOT
      -> SELF CHECK
      -> STAND
      -> MOVE
      -> SENSOR EVENT
      -> RESCUE BEHAVIOR
      -> REPORT STATUS

## 15. Golden debugging rule

Fix the smallest layer that is actually broken.

    Power
      -> Wiring
      -> Hardware driver
      -> ServoManager
      -> Calibration
      -> Kinematics
      -> MotionController
      -> Sensor/Rescue logic
      -> Demo

Do not rewrite the whole project because one servo channel is inverted.

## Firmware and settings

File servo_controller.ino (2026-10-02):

#include <Arduino.h>

#include "config.h"
#include "MotionController.h"
#include "PCA9685ServoDriver.h"
#include "ImuInterface.h"
#include "EnvironmentalSensors.h"
#include "CameraInterface.h"
#include "ThermalInterface.h"
#include "MotionSafety.h"
#include "HardwareStatus.h"
#include "RobotCore.h"
#include "RobotWebServer.h"
#include "Perception.h"
#include "ColorSensorInterface.h"

MotionController motionController;
PCA9685ServoDriver pca9685;
ImuInterface imu;
EnvironmentalSensors environmental;
CameraInterface camera;
ThermalInterface thermal;
MotionSafety motionSafety;
RobotCore robotCore(motionController, motionSafety, imu, environmental, camera, thermal);
RobotWebServer webServer(robotCore, motionController, motionSafety);

String serialBuffer;
bool safetyStopLatched = false;
CompetitionInputs competitionInputs;
WorldState perceptionInput;
unsigned long lastTelemetryMs = 0;
unsigned long lastMotionMs = 0;

String jsonValue(const String& json, const String& key)
{
    const String needle = String("\"") + key + "\":\"";
    const int startIndex = json.indexOf(needle);

    if (startIndex < 0) {
        return "";
    }

    const int valueStart = startIndex + needle.length();
    const int valueEnd = json.indexOf("\"", valueStart);

    if (valueEnd < 0) {
        return "";
    }

    return json.substring(valueStart, valueEnd);
}

void processJsonPacket(const String& packet)
{
    String command = jsonValue(packet, "command");
    command.toUpperCase();

    if (command == "STOP") {
        safetyStopLatched = true;
        motionSafety.emergencyStop();
        motionController.disable();
        Serial.println("{\"type\":\"ack\",\"command\":\"STOP\",\"ok\":true}");
        return;
    }

    if (command == "RESUME") {
        motionSafety.resume();
        safetyStopLatched = false;
        motionController.enable();
        Serial.println("{\"type\":\"ack\",\"command\":\"RESUME\",\"ok\":true}");
        return;
    }

    if (command == "ENABLE") {
        if (safetyStopLatched || !motionSafety.allowed()) {
            Serial.println("{\"type\":\"error\",\"error\":\"SAFETY_BLOCK\"}");
            return;
        }

        motionController.enable();
        motionSafety.noteMotionCommand();
        Serial.println("{\"type\":\"ack\",\"command\":\"ENABLE\",\"ok\":true}");
        return;
    }

    if (command == "CENTER") {
        if (safetyStopLatched || !motionSafety.allowed()) {
            Serial.println("{\"type\":\"ack\",\"command\":\"CENTER\",\"ok\":false,\"error\":\"E_STOP\"}");
            return;
        }

        motionController.center();
        motionSafety.noteMotionCommand();
        Serial.println("{\"type\":\"ack\",\"command\":\"CENTER\",\"ok\":true}");
        return;
    }

    if (command == "STAND") {
        if (safetyStopLatched || !motionSafety.allowed()) {
            Serial.println("{\"type\":\"ack\",\"command\":\"STAND\",\"ok\":false,\"error\":\"E_STOP\"}");
            return;
        }

        motionController.stand();
        motionSafety.noteMotionCommand();
        Serial.println("{\"type\":\"ack\",\"command\":\"STAND\",\"ok\":true}");
        return;
    }

    if (command == "MISSION") {
        String mode = jsonValue(packet, "mode");

        if (robotCore.setMode(mode)) {
            Serial.printf(
                "{\"type\":\"ack\",\"command\":\"MISSION\",\"ok\":true,\"mode\":\"%s\"}\n",
                robotCore.modeName().c_str()
            );
        } else {
            Serial.println("{\"type\":\"ack\",\"command\":\"MISSION\",\"ok\":false}");
        }

        return;
    }

    if (command == "GOAL") {
        String goal = jsonValue(packet, "goal");

        if (robotCore.setGoal(goal)) {
            Serial.printf(
                "{\"type\":\"ack\",\"command\":\"GOAL\",\"ok\":true,\"goal\":\"%s\",\"action\":\"%s\"}\n",
                robotCore.goalName().c_str(),
                robotCore.actionName().c_str()
            );
        } else {
            Serial.println("{\"type\":\"ack\",\"command\":\"GOAL\",\"ok\":false}");
        }

        return;
    }

    if (command == "RESCUE_DONE") {
        robotCore.completeRescue();
        Serial.println("{\"type\":\"ack\",\"command\":\"RESCUE_DONE\",\"ok\":true}");
        return;
    }

    if (command == "GAIT") {
        String mode = jsonValue(packet, "mode");
        mode.toUpperCase();

        if (safetyStopLatched || !motionSafety.allowed()) {
            Serial.println("{\"type\":\"ack\",\"command\":\"GAIT\",\"ok\":false,\"error\":\"E_STOP\"}");
            return;
        }

        if (
            mode != "WALK" &&
            mode != "SLOW_WALK" &&
            mode != "SEARCH" &&
            mode != "RESCUE"
        ) {
            Serial.println("{\"type\":\"ack\",\"command\":\"GAIT\",\"ok\":false,\"error\":\"BAD_MODE\"}");
            return;
        }

        motionController.setGait(mode);
        motionSafety.noteMotionCommand();

        Serial.printf(
            "{\"type\":\"ack\",\"command\":\"GAIT\",\"ok\":true,\"mode\":\"%s\"}\n",
            mode.c_str()
        );

        return;
    }

    Serial.println("{\"type\":\"error\",\"error\":\"UNKNOWN_COMMAND\"}");
}

void emitTelemetry()
{
    if (millis() - lastTelemetryMs < 1000) {
        return;
    }

    lastTelemetryMs = millis();

    HardwareStatus status = {
        pca9685.available(),
        false,
        false,
        false,
        false,
        false,
        motionSafety.allowed()
    };

    Serial.printf(
        "{\"type\":\"telemetry\",\"firmware\":\"%s\",\"safety_stop\":%s,\"gait\":\"%s\",\"phase\":%.3f,\"moving\":%s,\"hardware\":%s}\n",
        FIRMWARE_VERSION,
        safetyStopLatched ? "true" : "false",
        motionController.gait().mode(),
        motionController.gait().phase(),
        (motionController.gait().moving() || motionController.jumping()) ? "true" : "false",
        hardwareStatusJson(status).c_str()
    );

    const RobotCoreStatus core = robotCore.status();

    Serial.printf(
        "{\"type\":\"core\",\"phase\":\"%s\",\"mode\":\"%s\",\"goal\":\"%s\",\"action\":\"%s\",\"active\":%s,\"person\":%s,\"thermal\":%s,\"healthy\":%s,\"cycle\":%lu}\n",
        robotCore.phaseName().c_str(),
        robotCore.modeName().c_str(),
        robotCore.goalName().c_str(),
        robotCore.actionName().c_str(),
        core.missionActive ? "true" : "false",
        core.personDetected ? "true" : "false",
        core.thermalSignature ? "true" : "false",
        !core.fault ? "true" : "false",
        static_cast<unsigned long>(core.cycle)
    );
}

void printHelp()
{
    Serial.println();
    Serial.println("================================================");
    Serial.println("          AUTONOMOUS QUADRUPED ROBOT");
    Serial.println("================================================");
    Serial.println("SYSTEM");
    Serial.println("  help | status | center | stand | enable | disable | debug");
    Serial.println("  stop | resume | jump");
    Serial.println("    jump = CROUCH -> LOAD -> PUSH -> FLIGHT -> TUCK -> LAND -> ABSORB -> RECOVER");
    Serial.println();
    Serial.println("AUTONOMY");
    Serial.println("  goal RESCUE");
    Serial.println("  goal PATROL");
    Serial.println("  goal RETURN_HOME");
    Serial.println("  goal DEMO");
    Serial.println("  found | rescue_done | home | ai_status | reset_mission");
    Serial.println();
    Serial.println("COMPETITION");
    Serial.println("  comp_autonomous | comp_driver | comp_endgame | comp_finish | comp_status");
    Serial.println("  sensor <name> <0|1>  (simulator/test input)");
    Serial.println("  color <RED|GREEN|BLUE|YELLOW|BLACK|WHITE|UNKNOWN> <confidence>");
    Serial.println("  rgb <r> <g> <b>  (RGB simulator/classifier)");
    Serial.println("  line <LEFT|CENTER|RIGHT|INTERSECTION|LOST>");
    Serial.println("  perception_status");
    Serial.println();
    Serial.println("MISSION");
    Serial.println("  mission <IDLE|PATROL|SEARCH|RESCUE|RETURN_HOME>");
    Serial.println();
    Serial.println("SERVO");
    Serial.println("  servo <channel> <angle>");
    Serial.println("  leg <FL|FR|RL|RR> <C> <F> <T>");
    Serial.println();
    Serial.println("CALIBRATION");
    Serial.println("  cal | cal <channel>");
    Serial.println("  caloffset <channel> <offset>");
    Serial.println("  calinvert <channel> <0|1>");
    Serial.println("  callimit <channel> <min> <max>");
    Serial.println();
    Serial.println("KINEMATICS");
    Serial.println("  ik <x> <y> <z>");
    Serial.println("  ikleg <FL|FR|RL|RR> <x> <y> <z>");
    Serial.println("  pose <FL|FR|RL|RR> <x> <y> <z>");
    Serial.println();
    Serial.println("GAIT");
    Serial.println("  gait <WALK|SLOW_WALK|SEARCH|RESCUE>");
    Serial.println("================================================");
    Serial.println();
}

void processCommand(String command)
{
    command.trim();

    if (command.startsWith("{")) {
        processJsonPacket(command);
        return;
    }

    if (command.length() == 0) {
        return;
    }

    Serial.printf("[CMD] %s\n", command.c_str());

    if (command == "comp_autonomous") {
        robotCore.startAutonomous();
        Serial.println("[COMP] AUTONOMOUS started");
        return;
    }

    if (command == "comp_driver") {
        robotCore.startDriverControl();
        Serial.println("[COMP] DRIVER_CONTROL started");
        return;
    }

    if (command == "comp_endgame") {
        robotCore.startEndGame();
        Serial.println("[COMP] END_GAME started");
        return;
    }

    if (command == "comp_finish") {
        robotCore.finishCompetition();
        Serial.println("[COMP] FINISHED");
        return;
    }

    if (command.startsWith("rgb ")) {
        int r=0,g=0,b=0;
        if (sscanf(command.c_str(), "rgb %d %d %d", &r, &g, &b) == 3) {
            RGBReading rgb{static_cast<uint16_t>(max(0,r)), static_cast<uint16_t>(max(0,g)), static_cast<uint16_t>(max(0,b)), true};
            float confidence=0.0f;
            perceptionInput.targetColor.color=ColorSensorInterface::classify(rgb, confidence);
            perceptionInput.targetColor.confidence=confidence;
            perceptionInput.targetColor.valid=true;
            robotCore.setPerceptionInput(perceptionInput);
            Serial.printf("[PERCEPTION] rgb=%d,%d,%d -> %s confidence=%.2f\n",
                r,g,b,Perception::colorName(perceptionInput.targetColor.color),confidence);
        }
        return;
    }

    if (command.startsWith("color ")) {
        char color[16];
        float confidence = 1.0f;
        if (sscanf(command.c_str(), "color %15s %f", color, &confidence) >= 1) {
            perceptionInput.targetColor.color = Perception::parseColor(String(color));
            perceptionInput.targetColor.confidence = confidence;
            perceptionInput.targetColor.valid = true;
            robotCore.setPerceptionInput(perceptionInput);
            Serial.printf("[PERCEPTION] color=%s confidence=%.2f\n",
                          Perception::colorName(perceptionInput.targetColor.color),
                          confidence);
        }
        return;
    }

    if (command.startsWith("line ")) {
        String value = command.substring(5);
        value.trim();
        perceptionInput.line = Perception::parseLine(value);
        robotCore.setPerceptionInput(perceptionInput);
        Serial.printf("[PERCEPTION] line=%s\n", Perception::lineName(perceptionInput.line));
        return;
    }

    if (command.startsWith("sensor ")) {
        int value = 0;
        char name[24];
        if (sscanf(command.c_str(), "sensor %23s %d", name, &value) == 2) {
            const bool v = value != 0;
            String n(name); n.toUpperCase();
            if (n == "LINE") competitionInputs.lineDetected = v;
            else if (n == "INTERSECTION") competitionInputs.intersectionDetected = v;
            else if (n == "OBSTACLE") competitionInputs.obstacleDetected = v;
            else if (n == "TARGET") competitionInputs.targetDetected = v;
            else if (n == "PICKED") competitionInputs.targetPicked = v;
            else if (n == "CLASSIFIED") competitionInputs.targetClassified = v;
            else if (n == "PLACED") competitionInputs.targetPlaced = v;
            else if (n == "ALL_DONE") competitionInputs.allAutonomousTasksDone = v;
            else if (n == "ENDGAME") competitionInputs.endGameReady = v;
            else if (n == "HOME") competitionInputs.homeDetected = v;
            else { Serial.println("[COMP] unknown sensor"); return; }
            robotCore.setCompetitionInput(competitionInputs);
            Serial.printf("[COMP] sensor %s=%s\n", n.c_str(), v ? "true" : "false");
        } else {
            Serial.println("[COMP] usage: sensor <line|intersection|obstacle|target|picked|classified|placed|all_done|endgame|home> <0|1>");
        }
        return;
    }

    if (command == "comp_status") {
        Serial.printf("[COMP] phase=%s goal=%s action=%s\n", robotCore.phaseName().c_str(), robotCore.goalName().c_str(), robotCore.actionName().c_str());
        return;
    }

    if (command == "perception_status") {
        const WorldState& w = robotCore.worldState();
        Serial.printf("[PERCEPTION] line=%s color=%s conf=%.2f target=%s picked=%s placed=%s obstacle=%s home=%s\n",
            Perception::lineName(w.line), Perception::colorName(w.targetColor.color), w.targetColor.confidence,
            w.targetDetected?"true":"false", w.targetPicked?"true":"false", w.targetPlaced?"true":"false",
            w.obstacleDetected?"true":"false", w.homeDetected?"true":"false");
        return;
    }

    if (command == "help") {
        printHelp();
        return;
    }

    if (command == "status") {
        motionController.status();
        return;
    }

    if (command == "mission_status" || command == "ai_status") {
        const RobotCoreStatus state = robotCore.status();

        Serial.printf(
            "[AI] goal=%s action=%s mode=%s active=%s person=%s thermal=%s healthy=%s cycle=%lu\n",
            robotCore.goalName().c_str(),
            robotCore.actionName().c_str(),
            robotCore.modeName().c_str(),
            state.missionActive ? "true" : "false",
            state.personDetected ? "true" : "false",
            state.thermalSignature ? "true" : "false",
            !state.fault ? "true" : "false",
            static_cast<unsigned long>(state.cycle)
        );

        return;
    }

    if (command == "reset_mission") {
        robotCore.resetMission();
        Serial.println("[AI] mission reset");
        return;
    }

    if (command == "found") {
        if (robotCore.reportPerson()) {
            Serial.println("[AI] target detected -> RESCUE");
        } else {
            Serial.println("[AI] target report rejected");
        }

        return;
    }

    if (command == "rescue_done") {
        robotCore.completeRescue();
        Serial.println("[AI] rescue complete -> next decision");
        return;
    }

    if (command == "home") {
        robotCore.returnHome();
        Serial.println("[AI] RETURN_HOME requested");
        return;
    }

    if (command.startsWith("goal ")) {
        String goal = command.substring(5);
        goal.trim();

        if (robotCore.setGoal(goal)) {
            Serial.printf(
                "[AI] goal=%s action=%s mode=%s\n",
                robotCore.goalName().c_str(),
                robotCore.actionName().c_str(),
                robotCore.modeName().c_str()
            );
        } else {
            Serial.println("[AI] goal rejected");
        }

        return;
    }

    if (command.startsWith("mission ")) {
        String mode = command.substring(8);
        mode.trim();

        if (robotCore.setMode(mode)) {
            Serial.printf("[CORE] mode -> %s\n", robotCore.modeName().c_str());
        } else {
            Serial.println("[CORE] mission mode rejected");
        }

        return;
    }

    if (command == "debug") {
        motionController.debug();
        return;
    }

    if (command == "center") {
        if (safetyStopLatched || !motionSafety.allowed()) {
            Serial.println("[SAFETY] E-STOP active");
            return;
        }

        motionController.center();
        motionSafety.noteMotionCommand();
        return;
    }

    if (command == "stand") {
        if (safetyStopLatched || !motionSafety.allowed()) {
            Serial.println("[SAFETY] E-STOP active");
            return;
        }

        motionController.stand();
        motionSafety.noteMotionCommand();
        return;
    }

    if (command == "enable") {
        if (safetyStopLatched || !motionSafety.allowed()) {
            Serial.println("[SAFETY] enable blocked");
            return;
        }

        motionController.enable();
        motionSafety.noteMotionCommand();
        return;
    }

    if (command == "disable") {
        motionController.disable();
        return;
    }

    if (command == "jump") {
        if (safetyStopLatched || !motionSafety.allowed()) {
            Serial.println("[SAFETY] jump blocked");
            return;
        }

        motionController.jump();
        motionSafety.noteMotionCommand();
        return;
    }
\n    if (command == "stop") {
        safetyStopLatched = true;
        motionSafety.emergencyStop();
        motionController.disable();
        Serial.println("[SAFETY] E-STOP");
        return;
    }

    if (command == "resume") {
        motionSafety.resume();
        safetyStopLatched = false;
        motionController.enable();
        Serial.println("[SAFETY] RESUMED");
        return;
    }

    int channel;
    int angle;
    int offset;
    int invert;
    int minAngle;
    int maxAngle;

    if (command == "cal") {
        motionController.printCalibration();
        return;
    }

    if (sscanf(command.c_str(), "cal %d", &channel) == 1) {
        motionController.printCalibration(channel);
        return;
    }

    if (sscanf(command.c_str(), "caloffset %d %d", &channel, &offset) == 2) {
        motionController.setCalibrationOffset(channel, offset);
        return;
    }

    if (sscanf(command.c_str(), "calinvert %d %d", &channel, &invert) == 2) {
        motionController.setCalibrationInvert(channel, invert != 0);
        return;
    }

    if (sscanf(command.c_str(), "callimit %d %d %d", &channel, &minAngle, &maxAngle) == 3) {
        motionController.setCalibrationLimits(channel, minAngle, maxAngle);
        return;
    }

    if (sscanf(command.c_str(), "servo %d %d", &channel, &angle) == 2) {
        if (safetyStopLatched) {
            Serial.println("[SAFETY] E-STOP active");
            return;
        }

        motionController.setServo(channel, angle);
        return;
    }

    char name[4];
    int coxa;
    int femur;
    int tibia;

    if (sscanf(command.c_str(), "leg %3s %d %d %d", name, &coxa, &femur, &tibia) == 4) {
        motionController.setLeg(String(name), coxa, femur, tibia);
        return;
    }

    float x;
    float y;
    float z;

    if (sscanf(command.c_str(), "ik %f %f %f", &x, &y, &z) == 3) {
        motionController.testIK(x, y, z);
        return;
    }

    if (sscanf(command.c_str(), "ikleg %3s %f %f %f", name, &x, &y, &z) == 4) {
        motionController.setLegIK(String(name), x, y, z);
        return;
    }

    if (sscanf(command.c_str(), "pose %3s %f %f %f", name, &x, &y, &z) == 4) {
        motionController.setFootTarget(String(name), x, y, z);
        return;
    }

    char gaitMode[16];

    if (sscanf(command.c_str(), "gait %15s", gaitMode) == 1) {
        if (safetyStopLatched || !motionSafety.allowed()) {
            Serial.println("[SAFETY] gait blocked");
            return;
        }

        motionController.setGait(String(gaitMode));
        motionSafety.noteMotionCommand();
        return;
    }

    Serial.println("[ERROR] Unknown command. Type 'help'.");
}
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
void loop()
{
    webServer.update();
    emitTelemetry();

    if (motionSafety.timedOut() && !safetyStopLatched) {
        safetyStopLatched = true;
        motionSafety.emergencyStop();
        motionController.disable();
        robotCore.stop();
        Serial.println("{\"type\":\"safety\",\"event\":\"MOTION_TIMEOUT\"}");
    }

    const unsigned long now = millis();

    if (
        now - lastMotionMs >= MOTION_UPDATE_MS &&
        !safetyStopLatched &&
        motionSafety.allowed()
    ) {
        const float dt =
            static_cast<float>(now - lastMotionMs) / 1000.0f;

        lastMotionMs = now;
        robotCore.update(dt);
        if (motionController.jumping()) {
            // Keep the safety watchdog alive only while the bounded jump
            // state machine is actively producing motion commands.
            motionSafety.noteMotionCommand();
        }
    }

    while (Serial.available()) {
        const char c = static_cast<char>(Serial.read());

        if (c == '\n' || c == '\r') {
            if (serialBuffer.length() > 0) {
                processCommand(serialBuffer);
                serialBuffer = "";
            }
        } else {
            serialBuffer += c;

            if (serialBuffer.length() > 128) {
                serialBuffer = "";
                Serial.println("[ERROR] Command too long");
            }
        }
    }
}

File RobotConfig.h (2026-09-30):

#pragma once

#include <stdint.h>

// Single source of truth for the 35 cm competition robot.
namespace RobotConfig {

constexpr float MAX_LENGTH_MM = 350.0f;
constexpr float MAX_WIDTH_MM  = 350.0f;
constexpr float MAX_HEIGHT_MM = 350.0f;

constexpr float BODY_LENGTH_MM = 150.0f;
constexpr float BODY_WIDTH_MM  = 105.0f;
constexpr float BODY_HEIGHT_MM = 45.0f;

constexpr float COXA_MM  = 35.0f;
constexpr float FEMUR_MM = 65.0f;
constexpr float TIBIA_MM = 85.0f;

constexpr uint8_t LEG_COUNT = 4;
constexpr uint8_t DOF_PER_LEG = 3;
constexpr uint8_t SERVO_COUNT = LEG_COUNT * DOF_PER_LEG;

constexpr float SERVO_MIN_DEG = 0.0f;
constexpr float SERVO_MAX_DEG = 180.0f;
constexpr float DEFAULT_SERVO_DEG = 90.0f;

// Logical joint limits. Mechanical calibration can narrow these further.
constexpr float COXA_MIN_DEG  = 15.0f;
constexpr float COXA_MAX_DEG  = 165.0f;
constexpr float FEMUR_MIN_DEG = 15.0f;
constexpr float FEMUR_MAX_DEG = 165.0f;
constexpr float TIBIA_MIN_DEG = 10.0f;
constexpr float TIBIA_MAX_DEG = 170.0f;

// Conservative workspace for the 35 cm frame.
constexpr float FOOT_MIN_RADIUS_MM = 30.0f;
constexpr float FOOT_MAX_RADIUS_MM = 135.0f;
constexpr float FOOT_MIN_Z_MM = -125.0f;
constexpr float FOOT_MAX_Z_MM = -45.0f;

constexpr float DEFAULT_BODY_Z_MM = -90.0f;
constexpr float DEFAULT_STEP_LENGTH_MM = 24.0f;
constexpr float DEFAULT_STEP_HEIGHT_MM = 18.0f;
constexpr float DEFAULT_GAIT_FREQUENCY_HZ = 1.10f;

constexpr float MAX_STEP_LENGTH_MM = 45.0f;
constexpr float MAX_STEP_HEIGHT_MM = 28.0f;
constexpr float MAX_GAIT_FREQUENCY_HZ = 2.0f;

constexpr float MAX_COMMAND_SPEED_SCALE = 1.0f;
constexpr float MIN_SAFE_BATTERY_PERCENT = 15.0f;

constexpr uint32_t CONTROL_PERIOD_MS = 20;
constexpr uint32_t TELEMETRY_PERIOD_MS = 100;

constexpr uint8_t SERVO_FL_COXA = 0;
constexpr uint8_t SERVO_FL_FEMUR = 1;
constexpr uint8_t SERVO_FL_TIBIA = 2;
constexpr uint8_t SERVO_FR_COXA = 3;
constexpr uint8_t SERVO_FR_FEMUR = 4;
constexpr uint8_t SERVO_FR_TIBIA = 5;
constexpr uint8_t SERVO_RL_COXA = 6;
constexpr uint8_t SERVO_RL_FEMUR = 7;
constexpr uint8_t SERVO_RL_TIBIA = 8;
constexpr uint8_t SERVO_RR_COXA = 9;
constexpr uint8_t SERVO_RR_FEMUR = 10;
constexpr uint8_t SERVO_RR_TIBIA = 11;

} // namespace RobotConfig

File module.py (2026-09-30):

#!/usr/bin/env python3
"""
XZORT Rescue Quadruped CAD build entry point.

This file is intentionally the single Python entry point used by build.sh.
It discovers the existing CAD generator in the repository, runs it, and
verifies that build output contains only STL/STEP artifacts.

Expected output directory:
    out/
"""

from __future__ import annotations

import os
import shutil
import subprocess
import sys
from pathlib import Path


ROOT = Path(__file__).resolve().parent
OUT = ROOT / "out"

# Candidate existing CAD entry points. The first existing one is used.
CANDIDATES = [
    ROOT / "main.py",
    ROOT / "cad" / "main.py",
    ROOT / "CAD" / "main.py",
    ROOT / "src" / "main.py",
    ROOT / "scripts" / "main.py",
]


def log(message: str) -> None:
    print(f"[XZORT-CAD] {message}", flush=True)


def find_entrypoint() -> Path:
    for path in CANDIDATES:
        if path.is_file() and path.resolve() != Path(__file__).resolve():
            return path

    # Fall back to a shallow repository scan without touching .git/out.
    for path in sorted(ROOT.rglob("*.py")):
        if any(part in {".git", "out", "__pycache__", ".venv", "venv"} for part in path.parts):
            continue
        if path.name == "main.py":
            return path

    raise FileNotFoundError(
        "Khong tim thay CAD entry point (main.py). "
        "Hay dat generator chinh cua CAD vao root/cad/src va dat ten main.py."
    )


def clean_output() -> None:
    OUT.mkdir(parents=True, exist_ok=True)

    # Never delete source files here. Only remove old generated CAD artifacts.
    for item in OUT.iterdir():
        if item.is_file() and item.suffix.lower() in {".stl", ".step", ".stp"}:
            item.unlink()


def run_generator(entrypoint: Path) -> None:
    log(f"Generator: {entrypoint.relative_to(ROOT)}")
    env = os.environ.copy()
    env["XZORT_ROOT"] = str(ROOT)
    env["XZORT_OUT"] = str(OUT)

    result = subprocess.run(
        [sys.executable, str(entrypoint)],
        cwd=str(ROOT),
        env=env,
    )
    if result.returncode != 0:
        raise RuntimeError(f"CAD generator failed with exit code {result.returncode}")


def verify_output() -> None:
    allowed = {".stl", ".step", ".stp"}
    generated = [p for p in OUT.rglob("*") if p.is_file()]

    bad = [p for p in generated if p.suffix.lower() not in allowed]
    if bad:
        names = ", ".join(str(p.relative_to(ROOT)) for p in bad)
        raise RuntimeError(f"out/ co file khong phai STL/STEP: {names}")

    cad_files = [p for p in generated if p.suffix.lower() in allowed]
    if not cad_files:
        raise RuntimeError("Build khong tao ra STL/STEP nao trong out/.")

    log(f"Generated {len(cad_files)} CAD file(s):")
    for p in sorted(cad_files):
        log(f"  - {p.relative_to(ROOT)}")


def main() -> int:
    log(f"Root: {ROOT}")
    clean_output()
    entrypoint = find_entrypoint()
    run_generator(entrypoint)
    verify_output()
    log("BUILD PASS")
    return 0


if __name__ == "__main__":
    try:
        raise SystemExit(main())
    except KeyboardInterrupt:
        log("Interrupted.")
        raise SystemExit(130)
    except Exception as exc:
        print(f"[XZORT-CAD] BUILD FAIL: {exc}", file=sys.stderr)
        raise SystemExit(1)

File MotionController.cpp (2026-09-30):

#include "MotionController.h"
#include "EnvironmentalSensors.h"
#include "ImuInterface.h"
#include "MotionSet.h"
#include "SafetyManager.h"
#include <math.h>

static EnvironmentalSensors environment;
static ImuInterface imu;
static MotionSet motionSet;
static SafetyManager safetyManager;

const uint8_t MotionController::SERVO_MAP[LEG_COUNT][3] = {
    {RobotConfig::SERVO_FL_COXA, RobotConfig::SERVO_FL_FEMUR, RobotConfig::SERVO_FL_TIBIA},
    {RobotConfig::SERVO_FR_COXA, RobotConfig::SERVO_FR_FEMUR, RobotConfig::SERVO_FR_TIBIA},
    {RobotConfig::SERVO_RL_COXA, RobotConfig::SERVO_RL_FEMUR, RobotConfig::SERVO_RL_TIBIA},
    {RobotConfig::SERVO_RR_COXA, RobotConfig::SERVO_RR_FEMUR, RobotConfig::SERVO_RR_TIBIA}
};

const char* const MotionController::LEG_NAMES[LEG_COUNT] = {"FL", "FR", "RL", "RR"};

MotionController::MotionController()
    : kinematics(RobotConfig::COXA_MM, RobotConfig::FEMUR_MM, RobotConfig::TIBIA_MM),
      jumpPhase(JumpPhase::IDLE), jumpPhaseStartedMs(0), jumpActive(false) {
    resetLegStates();
}

void MotionController::begin() {
    calibrator.begin();
    servoManager.begin();
    environment.begin();
    imu.begin();
    gaitController.reset();
    motionSet.reset();
    safetyManager.reset();
    resetLegStates();
    jumpPhase = JumpPhase::IDLE;
    jumpActive = false;
    Serial.println("[MOTION] 35cm motion stack initialized");
}

void MotionController::update(float dt) {
    motionSet.update(dt);
    if (!safetyManager.canMove()) return;

    if (jumpActive) {
        updateJump();
        return;
    }

    if (!gaitController.moving()) return;
    gaitController.update(dt);

    for (uint8_t i = 0; i < LEG_COUNT; ++i) {
        const FootTarget target = gaitController.target(static_cast<GaitLeg>(i));
        setFootTarget(static_cast<LegID>(i), target.x, target.y, target.z);
    }
}

void MotionController::resetLegStates() {
    for (uint8_t i = 0; i < LEG_COUNT; ++i)
        legs[i] = {RobotConfig::DEFAULT_SERVO_DEG, RobotConfig::DEFAULT_SERVO_DEG, RobotConfig::DEFAULT_SERVO_DEG};
}

int MotionController::parseLeg(const String& name) const {
    String n = name;
    n.trim();
    n.toUpperCase();
    if (n == "FL") return FL;
    if (n == "FR") return FR;
    if (n == "RL") return RL;
    if (n == "RR") return RR;
    return -1;
}

void MotionController::setServo(int channel, int rawAngle) {
    if (!servoManager.validChannel(channel) || !safetyManager.canMove()) return;
    if (!safetyManager.validateServoAngle(rawAngle)) return;

    const int calibrated = calibrator.apply(channel, rawAngle);
    if (!safetyManager.validateServoAngle(calibrated)) return;
    servoManager.setAngle(channel, calibrated);
}

bool MotionController::setLeg(LegID leg, int coxa, int femur, int tibia) {
    if (leg < FL || leg > RR || !safetyManager.canMove()) return false;
    if (!safetyManager.validateServoAngle(coxa) ||
        !safetyManager.validateServoAngle(femur) ||
        !safetyManager.validateServoAngle(tibia)) return false;

    legs[leg] = {static_cast<float>(coxa), static_cast<float>(femur), static_cast<float>(tibia)};
    setServo(SERVO_MAP[leg][0], coxa);
    setServo(SERVO_MAP[leg][1], femur);
    setServo(SERVO_MAP[leg][2], tibia);
    return true;
}

bool MotionController::setLeg(const String& name, int coxa, int femur, int tibia) {
    const int leg = parseLeg(name);
    return leg >= 0 && setLeg(static_cast<LegID>(leg), coxa, femur, tibia);
}

bool MotionController::solveIK(float x, float y, float z, JointAngles& result) const {
    result = kinematics.solve(x, y, z);
    return result.valid;
}

bool MotionController::validateFootTarget(float x, float y, float z) const {
    return safetyManager.validateFootTarget(x, y, z);
}

bool MotionController::setFootTarget(LegID leg, float x, float y, float z) {
    if (leg < FL || leg > RR || !safetyManager.canMove()) return false;
    if (!validateFootTarget(x, y, z)) return false;

    JointAngles result;
    if (!solveIK(x, y, z, result)) return false;

    return setLeg(leg,
        static_cast<int>(lroundf(result.coxa)),
        static_cast<int>(lroundf(result.femur)),
        static_cast<int>(lroundf(result.tibia)));
}

bool MotionController::setFootTarget(const String& name, float x, float y, float z) {
    const int leg = parseLeg(name);
    return leg >= 0 && setFootTarget(static_cast<LegID>(leg), x, y, z);
}

bool MotionController::setLegIK(LegID leg, float x, float y, float z) {
    return setFootTarget(leg, x, y, z);
}

bool MotionController::setLegIK(const String& name, float x, float y, float z) {
    return setFootTarget(name, x, y, z);
}

void MotionController::testIK(float x, float y, float z) const {
    JointAngles a;
    if (!solveIK(x, y, z, a)) {
        Serial.printf("[IK] INVALID target %.1f %.1f %.1f\n", x, y, z);
        return;
    }
    Serial.printf("[IK] %.1f %.1f %.1f -> C=%.1f F=%.1f T=%.1f\n", x, y, z, a.coxa, a.femur, a.tibia);
}
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

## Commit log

2026-09-27 Test Codex Connector write access
2026-09-27 Add rescue robot simulator: rescue_robot_demo/sensors.py
2026-09-27 Remove connector write test
2026-09-27 Add telemetry sensor simulation and robot state machine
2026-09-27 Integrate mission telemetry sensors and state machine
2026-09-27 fix: complete API safety and telemetry wiring
2026-09-27 feat: add safe JSON bridge protocol to ESP32 firmware
2026-09-27 fix: block manual motion while firmware e-stop is latched
    [servo_controller.ino]
2026-09-27 feat: implement guarded PCA9685 driver
2026-09-27 feat: add environmental sensor boundary
2026-09-27 feat: add environmental sensor stub
2026-09-27 feat: add IMU interface boundary
2026-09-27 feat: add IMU stub
2026-09-27 feat: connect ServoManager to guarded PCA9685 driver
2026-09-27 feat: initialize hardware sensor boundaries
2026-09-27 feat: add camera hardware boundary
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2026-09-27 fix: make PC bridge stdin command input functional
    [PCSerialBridge.py]
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2026-09-27 feat: add ESP32 telemetry link for Robot OS
2026-09-27 fix: enforce safety on manual enable and motion
    [servo_controller.ino]
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2026-09-27 fix(core): include math definitions for sensor validation
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2026-09-27 Fix firmware command parser and add autonomous goal control
    [servo_controller.ino]
2026-09-27 Fix and complete competition decision API
    [DecisionEngine.h]
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2026-09-27 Implement ESP32 Wi-Fi web control and chat UI
2026-09-27 Add competition controls, sensor simulation and phase telemetry
2026-09-27 fix: keep competition sensor inputs in perception state
2026-09-27 fix: restore autonomous command and telemetry newlines
    [servo_controller.ino]
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2026-09-27 fix: add optional Gemini API key configuration
    [config.h]
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2026-09-27 feat: track classified rescue targets in world state
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2026-09-27 fix: preserve legacy perception API while adding unified competition state
    [Perception.h]
2026-09-27 fix: make target color API backward compatible with simulator and web telemetry
    [Perception.h]
2026-09-27 refactor CAD module with centralized print parameters and cleaner geometry
2026-09-27 make CAD module print-ready for FDM with dedicated STL outputs
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2026-09-27 Upgrade CAD to dragon-style body tail and eye module V4
2026-09-27 fix V5 CAD null shape in hip bracket boolean cuts
2026-09-27 fix CAD V6 stable booleans and import-safe generation
2026-09-27 fix V6 hip fastener cut geometry
2026-09-27 stabilize V6 hip bracket OCC booleans
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2026-09-27 cad: reshape quadruped legs into angular spider-style links
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2026-09-27 cad: add dragon scales spikes and removable service mounts
2026-09-27 cad: remove generated STL and STEP artifacts
    [RescueQuadruped_Dragon_Body_MASTER.step]
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2026-09-27 cad: add explicit full body master assembly export
2026-09-27 chore: remove generated CAD STL STEP artifacts
    [RescueQuadruped_Dragon_Accessory_Kit_MASTER.step]
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2026-09-27 chore: purge generated STL STEP artifacts
    [RescueQuadruped_Dragon_Head_EyeHoles_PRINT.stl, RescueQuadruped_Dragon_Hip_Bracket_MASTER.step, RescueQuadruped_Dragon_Hip_Bracket_PRINT.stl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]
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2026-09-28 Redesign CAD with rounded dragon body and leg wing membranes
2026-09-28 Remove generated CAD body.step
    [body.step]
2026-09-28 Remove generated CAD body.stl
    [body.stl]
2026-09-28 Remove generated CAD body_scales.step
    [body_scales.step]
2026-09-28 Remove generated CAD body_scales.stl
    [body_scales.stl]
2026-09-28 Remove generated CAD cover_rail.step
    [cover_rail.step]
2026-09-28 Remove generated CAD cover_rail.stl
    [cover_rail.stl]
2026-09-28 Remove generated CAD dragon_spider_full.step
    [dragon_spider_full.step]
2026-09-28 Remove generated CAD dragon_spider_full.stl
    [dragon_spider_full.stl]
2026-09-28 Remove generated CAD foot.step
    [foot.step]
2026-09-28 Remove generated CAD foot.stl
    [foot.stl]
2026-09-28 Remove generated CAD foot_claw.step
    [foot_claw.step]
2026-09-28 Remove generated CAD foot_claw.stl
    [foot_claw.stl]
2026-09-28 Remove generated CAD head.step
    [head.step]
2026-09-28 Remove generated CAD head.stl
    [head.stl]
2026-09-28 Remove generated CAD lower_leg.step
    [lower_leg.step]
2026-09-28 Remove generated CAD lower_leg.stl
    [lower_leg.stl]
2026-09-28 Remove generated CAD neck.step
    [neck.step]
2026-09-28 Remove generated CAD neck.stl
    [neck.stl]
2026-09-28 Remove generated CAD neck_frill.step
    [neck_frill.step]
2026-09-28 Remove generated CAD neck_frill.stl
    [neck_frill.stl]
2026-09-28 Remove generated CAD sensor_pod.step
    [sensor_pod.step]
2026-09-28 Remove generated CAD sensor_pod.stl
    [sensor_pod.stl]
2026-09-28 Remove generated CAD shoulder.step
    [shoulder.step]
2026-09-28 Remove generated CAD shoulder.stl
    [shoulder.stl]
2026-09-28 Remove generated CAD tail.step
    [tail.step]
2026-09-28 Remove generated CAD tail.stl
    [tail.stl]
2026-09-28 Remove generated CAD tail_scales.step
    [tail_scales.step]
2026-09-28 Remove generated CAD tail_scales.stl
    [tail_scales.stl]
2026-09-28 Remove generated CAD upper_leg.step
    [upper_leg.step]
2026-09-28 Remove generated CAD upper_leg.stl
    [upper_leg.stl]
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2026-09-28 Update generated CAD 2026-09-28 17:06:37
    [body.step, body.stl, body_scales.step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]
2026-09-28 Redesign CAD as modular mechanical dragon armor V8
2026-09-28 Update generated CAD 2026-09-28 21:15:59
    [body.step, body.stl, body_belly_armor.step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]
2026-09-28 Generate mechanical dragon armor CAD
    [FL_coxa.step, FL_coxa.stl, FL_coxa_armor.step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]
2026-09-28 Generate rounded hollow modular dragon CAD
    [PRINT_FL_coxa.step, PRINT_FL_coxa.stl, PRINT_FL_coxa_armor.step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]
2026-09-28 Redesign rescue beast CAD to match dragon-spider concept
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2026-09-29 feat(cad): replace dragon-spider modul with 35cm competition-safe generator
2026-09-29 fix CAD assembly performance: use compound bounds instead of boolean fuse
2026-09-29 Fix assembly scaling about global origin
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2026-09-29 Generate competition-safe 35cm dragon-spider CAD
    [PRINT_FL_FOOT.step, PRINT_FL_FOOT.stl, PRINT_FL_SEGMENT_1_SHIELD.step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]
2026-09-29 Update generated CAD 2026-09-29 13:27:48
    [FL_coxa.step, FL_coxa.stl, FL_coxa_armor.step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]
2026-09-29 Build grouped 35cm rescue dragon CAD
    [FL_leg.stl, FR_leg.stl, PRINT_FL_FOOT.step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]
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2026-09-29 robot: route motion geometry and servo map through RobotConfig
2026-09-29 robot: adapt gait controller to centralized 35cm geometry
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2026-09-30 robot: correct tripod gait and 35cm foot geometry
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2026-09-30 chore(cad): add one-command build pull and push script
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2026-10-02 fix(firmware): repair jump command source formatting
    [servo_controller.ino]
2026-10-27 fix(cad): run canonical CAD generator and verify exports
2026-10-27 fix(cad): stop scaling mechanical interfaces out of tolerance
2026-10-27 fix(cad): preserve last outputs when geometry validation fails
2026-10-27 fix(build): include canonical CAD generator in commits
2026-10-27 docs: reset Bảng B purchase plan to 1M VND cap
2026-10-27 docs: supersede 5M BOM with 1M budget plan
2026-10-27 docs: add budget-first hardware and board selection gates
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2026-10-27 fix(cad): align generator docs and prevent stale exports masking failed builds
2026-10-27 fix(cad): report active firmware IK geometry consistently
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2026-10-27 docs: replace legacy 80cm concept with current build status
2026-10-27 docs: align wiring plan with budget and board selection
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
